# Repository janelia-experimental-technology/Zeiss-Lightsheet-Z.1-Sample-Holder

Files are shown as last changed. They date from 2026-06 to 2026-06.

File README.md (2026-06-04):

<div align="center">

<hr>

<h1>Z.1-Compatible Sample Holder</h1>

</div>

## Abstract

Selective Plane Illumination Microscopy (SPIM) is a powerful tool for volumetric imaging of cleared specimens. The Zeiss Lightsheet microscope Z.1 offers a commercial solution for SPIM imaging. The Z.1 presents sample mounting challenges, though. Users must position samples vertically and stabilize them for hours-long imaging sessions. We offer designs for a custom sample holder to mount cleared and expansion microscopy (ExM) samples on the Z.1 system.

## Purpose

A disposable or semi-disposable sample holder (shown in red in Figure 2) was needed to interface with the rotor post of the Z.1 microscope (shown in yellow in Figure 2). Two final versions have been developed - one to be printed and the other to be machined. The machined version will have a higher setup cost, but will be cheaper and more reliable in the long run.

Issues faced during development included wildly inconsistent tolerances between batches of printed lightsheet holders and deformations of the printed part during and after printing. Some major causes of tolerance issues include: the calibration state of the printer; support material residue on the printed part after post-processing; the orientation of the part in the printer; and the inconsistent pressure applied by the locating pin of the rotor post on the sample holder. Major causes of mid- and post-printing deformations were the orientation of the part in the printer and exposure of the printed parts to raw resin vapors and IPA cleaning solution.

Due to the frustration in achieving quality results with printed sample holders, a machined sample holder was designed to avoid printing process woes. The machined holder consists of a reusable metal base and a semi-disposable plastic platform. A new printed version was also worked up with new features that help mitigate some issues faced with the old printed versions.

<p align="center">
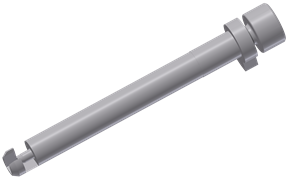
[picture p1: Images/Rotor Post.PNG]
Rotor Post to which the Lightsheet Holder is affixed
  
  <br>
  <em>Figure 1: Rotor Post to which the Lightsheet Holder is affixed</em>
</p>

<p align="center">
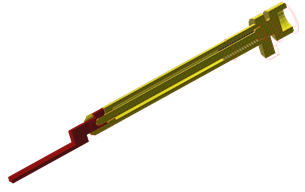
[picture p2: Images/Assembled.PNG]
Lightsheet Holder assembled to the Rotor Post, section view
  
  <br>
  <em>Figure 2: Lightsheet Holder assembled to the Rotor Post, section view*</em>
</p>

## Printed Version (V18R)

**Parts:**

- LIGHTSHEETHOLDER V18R

**Files:**

- V18R.STP
- V18R.STL
- V18R.PDF
- V18R - PRINTING DIRECTION.PDF

The advantage of the 3D printed version is that it can be fabricated in-house with a basic resin printer in one part without any assembly needed. Formlabs printers with Formlabs Clear resin are known to produce good results for these holders. Cheaper resin printers, like the Elegoo Mars, Anycubic Photon, or Phrozen Sonic Mini with AnyCubic Clear, NOVA3D Ultra-Clear, or Siraya Tech Blu Clear V2 resin, may also work well.

The printed version is known to work well when printed in Veroclear or Formlabs Clear, although Veroclear is recommended as the material is less susceptible to shattering on impact. Orientation is critical if the part is printed in Veroclear on a Polyjet printer as the material can swell anisotropically with repeated, prolonged exposure to saline solutions. Orientation does not matter when printed in Formlabs Clear and swelling is not observed with the Formlabs material, though there can be some unwanted deformation right off the printer due to the lower rigidity of the printer and absorption of resin vapors and IPA cleaning solution while the part is in its green state.

Forward the STL <u>or</u> STP file to your 3D printing service to have it 3D printed. The PDF file is also provided to help clarify the scale of the part for the printing service. If VeroClear is chosen, then see the "V18R - PRINTING DIRECTION.PDF" file for for the correct orientation or forward that document to your 3D printing service.

Any printing service capable of printing VeroClear will be able to process your parts, but Xometry is known to produce quality parts with quick turnaround.

<p align="center">
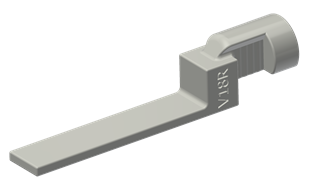
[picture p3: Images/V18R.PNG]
Printed Lightsheet Holder, version 18R
  
  <br>
  <em>Figure 3: Printed Lightsheet Holder, version 18R*</em>
</p>

## Machined Version (V20M)

**Parts:**

- LIGHTSHEETHOLDER V20M - BASE
- LIGHTSHEETHOLDER V20M - PLATFORM
- 2X 91771A054 0-80x3/16" Stainless Steel Pan Head Screw (from McMaster.com) https://www.mcmaster.com/91772A054/

**Files:**

- V20M - ASSEMBLY.PDF
- V20M - BASE.PDF
- V20M - BASE.STL
- V20M - BASE.STP
- V20M - PLATFORM.DXF
- V20M - PLATFORM.PDF
- V20M - PLATFORM.STP

The advantage of the machined version is that the part of the 3D-printed version of the holder that is most expensive to post-process has been confined to a durable, reusable, machinable part. The platform, onto which the samples are mounted, is a disposable acrylic part that can be lasercut in-house or cheaply lasercut by an outside service. The platform is held onto the base by a couple of 0-80 x 3/16" pan head screws.

Forward the STP <u>and</u> PDF files for the Base to your machining service to have the Base component fabricated. Forward the STP or DXF file of the Platform to your lasercutting service to have the Platform component fabricated.

Any prototyping fabricator should be able to take care of the Base part for you, but either Xometry or Protolabs are recommended. The Platform part is most cost effective if it can be lasercut in-house en masse from acrylic, but it can also be sent out for lasercutting, waterjetting, or machining from acrylic, polycarbonate, or stainless steel if an in-house lasercutter is not available. SendCutSend or Xometry is recommended for the platform.

<p align="center">
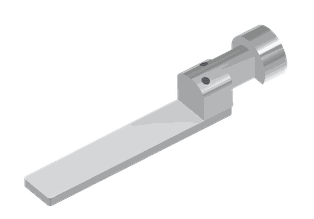
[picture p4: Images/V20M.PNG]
Printed Lightsheet Holder, version 20M
  
  <br>
  <em>Figure 4: Machined Lightsheet Holder, version 20M*</em>
</p>

<hr>

<p><strong>Published:</strong> June 31, 2022 | JST</p>
<p><strong>Transferred to GitHub:</strong> June 4, 2026 | JST</p>

<hr>

## Use

Free to make for Non-Profit Research by downloading the design here . See included hardware license. Rights and designs available for Commercial License. Janelia makes no endorsements or guarantees of licensee products. 

Rights and designs available for Commercial License. Janelia makes no endorsements or guarantees of licensee products.

For inquiries, please contact innovation@janelia.hhmi.org and reference this repository.

To cite the designs, please use DOI: https://doi.org/10.25378/janelia.32582463

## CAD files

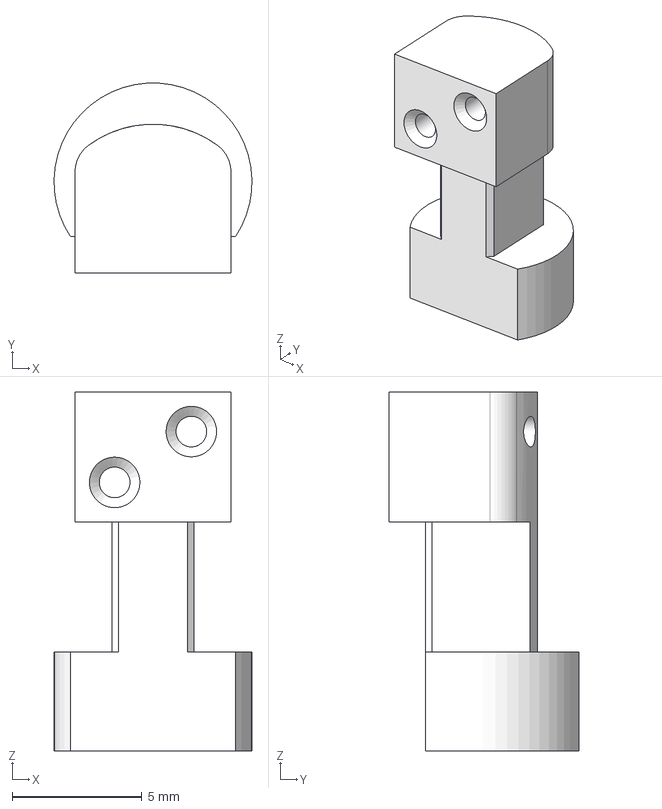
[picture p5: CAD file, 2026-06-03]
Part Files/V20M - BASE.stp
7.62 x 7.30 x 13.8 mm

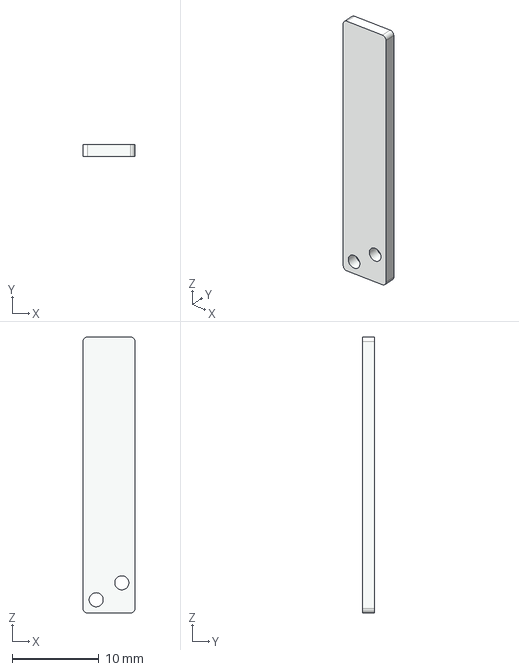
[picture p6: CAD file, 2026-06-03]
Part Files/V20M - PLATFORM.stp
6.00 x 1.40 x 31.8 mm

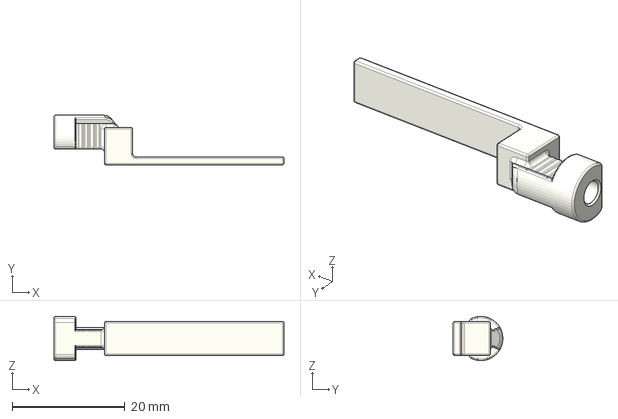
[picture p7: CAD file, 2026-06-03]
Part Files/V18R.stp
40.8 x 8.81 x 7.82 mm

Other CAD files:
Part Files/V20M - PLATFORM.dxf

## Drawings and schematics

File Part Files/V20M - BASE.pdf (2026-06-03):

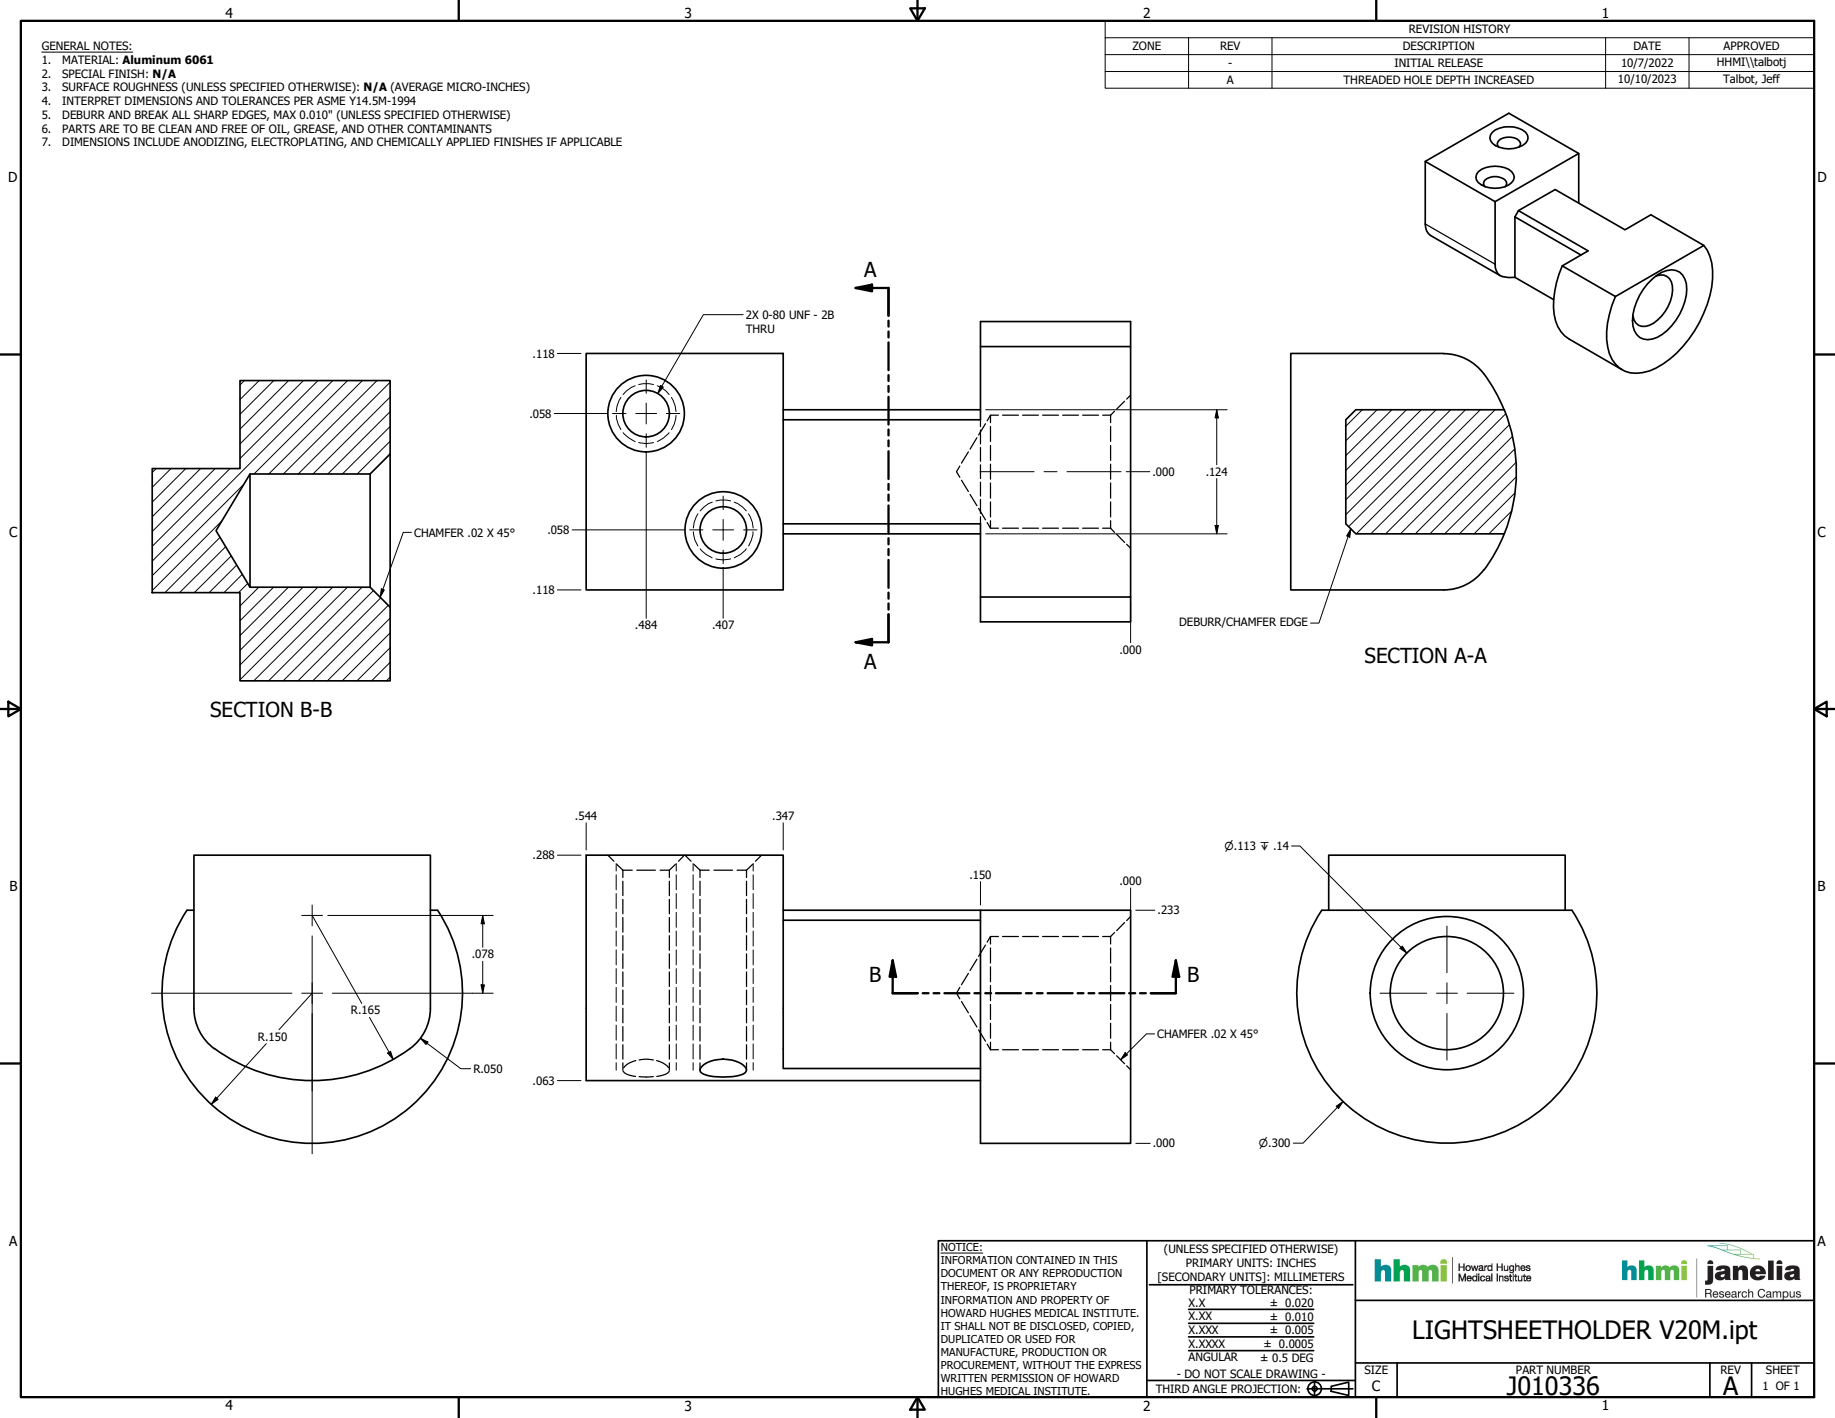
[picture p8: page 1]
SECTION A-A; SECTION B-B; PART NUMBER; 1 OF 1 THIRD ANGLE PROJECTION:; ± 0.020 ± 0.010 ± 0.005 ± 0.0005 ± 0.5 DEG; LIGHTSHEETHOLDER V20M.ipt; REVISION HISTORY; CHAMFER .02 X 45°; 2X 0-80 UNF - 2B

GENERAL NOTES:
1. MATERIAL: Aluminum 6061
2. SPECIAL FINISH: N/A
3. SURFACE ROUGHNESS (UNLESS SPECIFIED OTHERWISE): N/A (AVERAGE MICRO-INCHES)
4. INTERPRET DIMENSIONS AND TOLERANCES PER ASME Y14.5M-1994
5. DEBURR AND BREAK ALL SHARP EDGES, MAX 0.010" (UNLESS SPECIFIED OTHERWISE)
6. PARTS ARE TO BE CLEAN AND FREE OF OIL, GREASE, AND OTHER CONTAMINANTS
7. DIMENSIONS INCLUDE ANODIZING, ELECTROPLATING, AND CHEMICALLY APPLIED FINISHES IF APPLICABLE

ZONE | REV | DESCRIPTION | DATE | APPROVED

- | INITIAL RELEASE | 10/7/2022 | HHMI\\talbotj
A | THREADED HOLE DEPTH INCREASED | 10/10/2023 | Talbot, Jeff

DEBURR/CHAMFER EDGE

NOTICE:
INFORMATION CONTAINED IN THIS
DOCUMENT OR ANY REPRODUCTION
THEREOF, IS PROPRIETARY
INFORMATION AND PROPERTY OF
HOWARD HUGHES MEDICAL INSTITUTE.
IT SHALL NOT BE DISCLOSED, COPIED,
DUPLICATED OR USED FOR
MANUFACTURE, PRODUCTION OR
PROCUREMENT, WITHOUT THE EXPRESS
WRITTEN PERMISSION OF HOWARD
HUGHES MEDICAL INSTITUTE.

(UNLESS SPECIFIED OTHERWISE)
PRIMARY UNITS: INCHES
[SECONDARY UNITS]: MILLIMETERS
PRIMARY TOLERANCES:
X.XXX
X.XXXX
ANGULAR
- DO NOT SCALE DRAWING -
